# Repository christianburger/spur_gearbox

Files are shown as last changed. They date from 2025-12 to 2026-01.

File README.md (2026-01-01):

# Spur Gearbox for NEMA17 Motor

A fully parametric **3D printable single-stage spur gear reduction gearbox** designed in OpenSCAD, intended for NEMA17 stepper motors.

This design provides a clean, compact reduction using chamfered spur gears for smoother meshing, supported by 695ZZ bearings (5x13x4 mm). The split housing allows easy assembly, and the output shaft is designed for a 9 mm round shaft with setscrew.

**Gear ratio**: 32:12 ≈ **2.667:1** reduction

## Features

- Direct mount to standard NEMA17 motors (31 mm hole pattern)
- Input gear with D-shaft bore for standard 5 mm motor shafts
- Chamfered gears to reduce sharp edges and improve print quality/meshing
- Integrated bearing pockets and retainers for two 695ZZ bearings
- Setscrew hubs on both input and output gears
- Mounting holes on the output end (M4)
- Printed in two halves (top + bottom housing) for easy access

## Files

- `complete.gearbox.scad` – Full assembly view (open this to preview the complete gearbox)
- `housing_bottom.scad` – Bottom half of the housing
- `housing_top.scad` – Top half of the housing
- `input_gear_chamfered.scad` – Input gear (12 teeth) with hub and D-bore
- `output_gear_chamfered.scad` – Output gear (32 teeth) with hub
- `.stl` files – Pre-exported meshes ready for slicing/printing

## How to Generate STL Files and 3D Print

### Using OpenSCAD (recommended for latest/custom versions)

1. Install OpenSCAD (free from https://openscad.org/)
2. Open each part file you want to print:
   - `housing_bottom.scad`
   - `housing_top.scad`
   - `input_gear_chamfered.scad`
   - `output_gear_chamfered.scad`
   - (Optional: open `complete.gearbox.scad` first to preview the full assembly)
3. Press **F5** to preview the model
4. Press **F6** to render (this computes the full geometry – takes a few seconds)
5. Once rendered, go to **File > Export > Export as STL** and save the file
6. Repeat for each part

### Using Pre-exported STLs

The repository already includes ready-to-print STL files for all parts. Simply download them directly.

### Slicing and Printing Recommendations

- **Material**: PETG or PLA+ recommended for strength and durability (ABS/ASA also good if you have an enclosure)
- **Layer height**: 0.15–0.2 mm for good balance of strength and detail
- **Infill**: 30–50% (use more for gears if under heavy load)
- **Perimeters/Walls**: 3–4 for strength
- **Supports**: Usually minimal or none needed. Small tree supports may help under bearing bosses if your printer struggles with bridging
- **Orientation**: Print housing halves flat on the bed (large flat side down) for best strength
- **Brim**: Recommended for better bed adhesion on larger parts

## Required Hardware

- 2 × 695ZZ bearings (5 × 13 × 4 mm)
- M3 grub screw for input gear setscrew
- M4 or M5 grub screw for output shaft
- Optional: M3/M4 screws or glue to secure top and bottom housing together

## Customization

Parameters are defined at the top of the SCAD files. You can easily modify:
- Gear ratio (change tooth counts)
- Module (tooth size)
- Shaft diameters
- Clearances and tolerances for your printer

Open `complete.gearbox.scad` to visualize changes in the full assembly.

Enjoy the build! If you print it, feel free to share improvements. 🚀

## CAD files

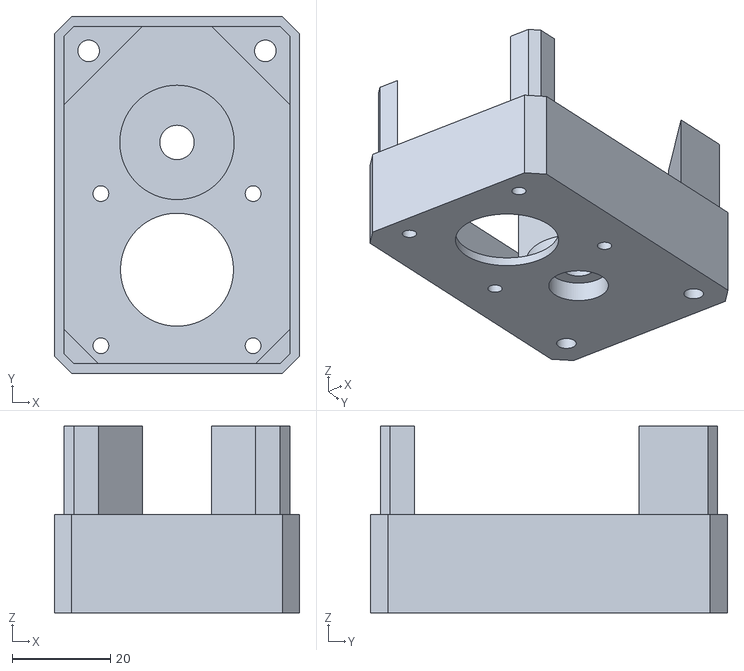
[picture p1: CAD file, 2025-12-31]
housing_bottom.stl
50.0 x 72.7 x 38.0

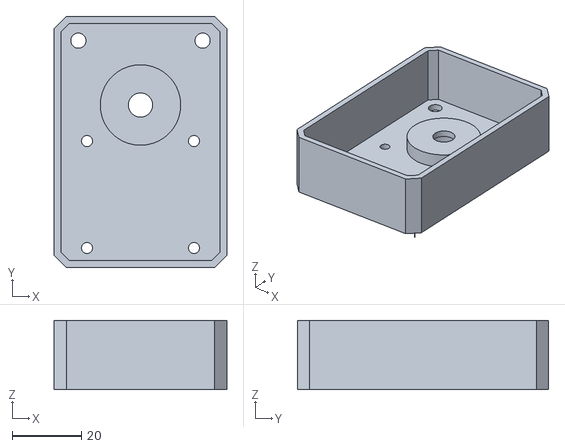
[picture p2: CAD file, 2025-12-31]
housing_top.stl
50.0 x 72.7 x 20.0

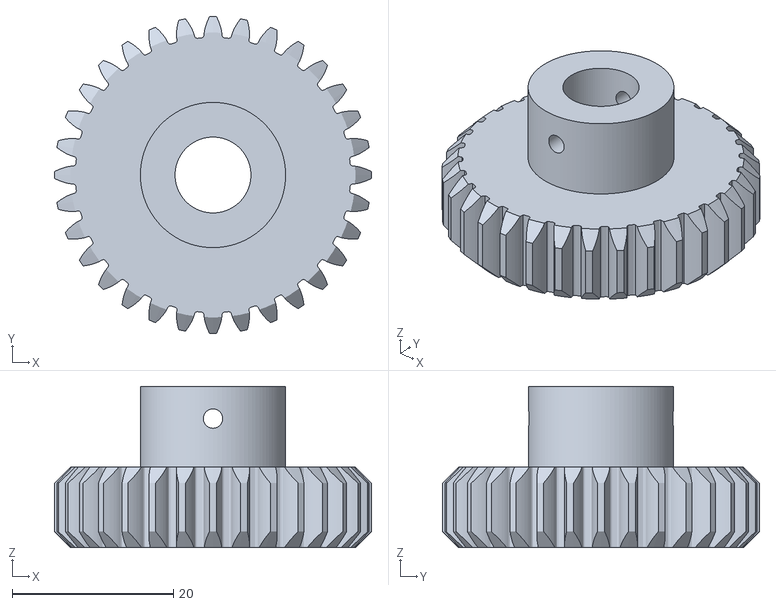
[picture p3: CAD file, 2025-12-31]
output_gear_chamfered.stl
39.3 x 39.3 x 20.0

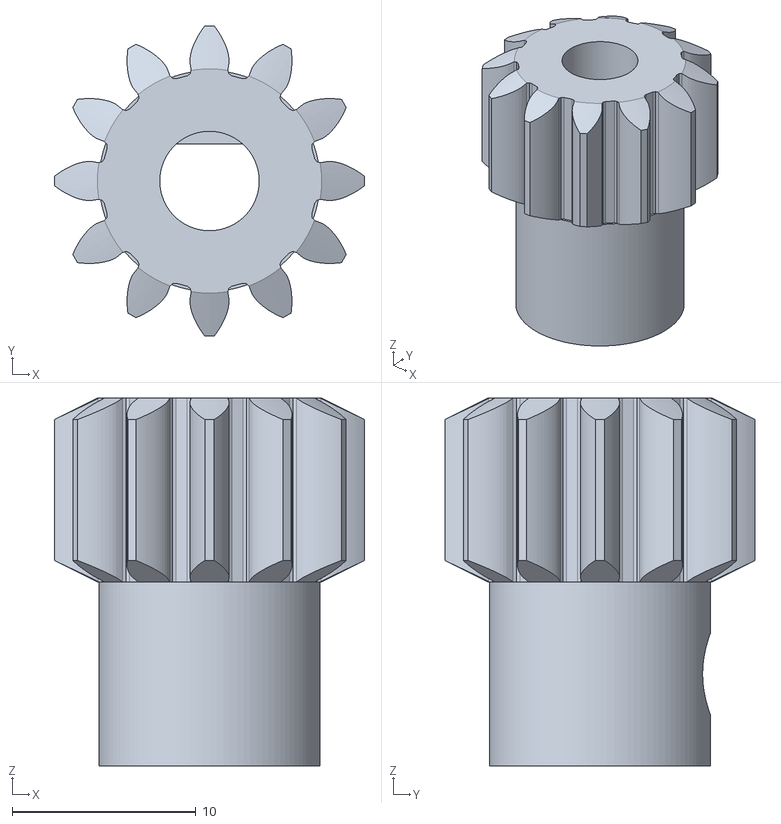
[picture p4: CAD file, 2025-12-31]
input_gear_chamfered.stl
16.9 x 16.9 x 20.0

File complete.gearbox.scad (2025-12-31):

// ============================================================================
// 4:1 LINEAR GEARBOX HOUSING
// ============================================================================
// BOSL2 library required
// Print TWICE to get both halves (identical halves)
// ============================================================================

include <BOSL2/std.scad>
include <BOSL2/gears.scad>

$fn = 100;

// ============================================================================
// TOLERANCES & CLEARANCES
// ============================================================================
// Clearance: Add to pockets/holes (makes them bigger for fit)
// Tolerance: Add to shaft bores (allows shaft to pass through)

clearance_bearing_pocket = 0.3;  // Bearing pocket clearance
clearance_screw_hole = 0.0;      // M3 screw hole clearance
clearance_boss_center = 0.3;     // Motor boss center clearance
tolerance_shaft = 0.4;           // Shaft bore tolerance
tolerance_output_bore = 0.4;     // Output gear bore tolerance

// ============================================================================
// GEAR PARAMETERS
// ============================================================================

teeth_input = 12;
teeth_output = 32;
gear_module = 1.156;
gear_thickness = 10;
gear_pressure_angle = 20;

// Calculated gear dimensions
pitch_radius_input = (gear_module * teeth_input) / 2;
pitch_radius_output = (gear_module * teeth_output) / 2;
outer_radius_input = (gear_module * (teeth_input + 2)) / 2;
outer_radius_output = (gear_module * (teeth_output + 2)) / 2;
center_distance = pitch_radius_input + pitch_radius_output + 0.5;

// ============================================================================
// BEARING SPECIFICATIONS (695ZZ: 5mm ID, 13mm OD, 4mm thickness)
// ============================================================================

bearing_id = 5;      // Inner diameter
bearing_od = 13;     // Outer diameter
bearing_thickness = 4;

// ============================================================================
// SHAFT & HUB PARAMETERS
// ============================================================================

// Input shaft (D-shaped)
shaft_diameter_input = 5.0;
shaft_flat_height = 4.0;  // D-shaft flat dimension
hub_diameter_input = 12;
hub_height_input = 10;

// Output shaft (round)
shaft_diameter_output = 9.0;
hub_diameter_output = 18;
hub_height_output = 10;

// Setscrews (M3 grub screws)
setscrew_output_diameter = 3.0;
setscrew_output_clearance = 0.6;  // Undersize for PETG shrinkage

// Setscrews (M5 grub screws)
setscrew_input_diameter = 5.0;
setscrew_input_clearance = 0.6;  // Undersize for PETG shrinkage

// Gear chamfers
chamfer_height = 2.0;
chamfer_angle = 45;
chamfer_base_radius_input = outer_radius_input - chamfer_height * tan(chamfer_angle);
chamfer_base_radius_output = outer_radius_output - chamfer_height * tan(chamfer_angle);
chamfer_base_radius_gear = outer_radius_input + 2;

// ============================================================================
// NEMA17 MOTOR PARAMETERS
// ============================================================================

nema17_body_size = 42.3;          // Standard NEMA17 body dimension
nema17_hole_spacing = 31;         // Mounting hole spacing
nema17_hole_diameter = 3.2;       // M3 mounting holes
nema17_boss_diameter = 23;        // Center boss clearance
nema17_boss_depth = 2.5;          // Boss pocket depth
nema17_hole_edge_distance = 5.65; // Distance from hole center to motor edge

// ============================================================================
// HOUSING DIMENSIONS
// ============================================================================


wall_to_gear_clearance = 6;
housing_width = 50;                // X dimension (matches NEMA17)

//housing_length = 56;

wall_thickness = 2;
floor_thickness = 2;

// Bearing pockets
bearing_pocket_depth = bearing_thickness + 0.5;
bearing_retainer_height = 2.0;     // Retainer ring height
bearing_retainer_id = 7.0;         // Retainer inner diameter
boss_diameter = bearing_od + clearance_bearing_pocket + 10;

clearance_internal_bottom = 1.5;   // Clearance below gears
clearance_internal_top = 1.5;      // Clearance above gears

box_height = (floor_thickness * 2 +          
              clearance_internal_bottom + 
              clearance_internal_top +
              max(hub_height_input, hub_height_output) + 
              gear_thickness + 
              bearing_retainer_height * 2 +
              bearing_pocket_depth * 2) / 2;

   
echo ("clearance_internal_bottom: ", clearance_internal_bottom)
echo ("clearance_internal_top", clearance_internal_top);
echo ("hub_height (max)", max(hub_height_input, hub_height_output));
echo ("gear_thickness: ", gear_thickness)
echo ("bearing_retainer_height (x2): ", bearing_retainer_height * 2);
echo ("bearing_pocket_depth: (x2)", bearing_pocket_depth * 2);   
echo ("\n\n>>>>> box_height: ", box_height);

// ============================================================================
// CALCULATED POSITIONS
// ============================================================================

// Input shaft position (centered on NEMA17 mounting pattern)
input_x = housing_width / 2;
input_y = nema17_hole_edge_distance + nema17_hole_spacing / 2;

// Output shaft position
output_x = input_x;
output_y = input_y + center_distance;

housing_length = output_y + outer_radius_output + wall_to_gear_clearance;


// NEMA17 mounting holes (31mm square pattern)
nema17_hole1_x = input_x - nema17_hole_spacing / 2;
nema17_hole1_y = input_y - nema17_hole_spacing / 2;
nema17_hole2_x = input_x + nema17_hole_spacing / 2;
nema17_hole2_y = input_y - nema17_hole_spacing / 2;
nema17_hole3_x = input_x - nema17_hole_spacing / 2;
nema17_hole3_y = input_y + nema17_hole_spacing / 2;
nema17_hole4_x = input_x + nema17_hole_spacing / 2;
nema17_hole4_y = input_y + nema17_hole_spacing / 2;

// Output end mounting holes (opposite end)
output_hole_edge_distance = 7;    // Distance from output hole center to wall edge
output_hole_diameter = 4.2;       // M4 mounting holes at output end
output_hole_tolerance = 0.2;      //clearance for M4 mounting holes at output end

output_hole1_x = output_hole_edge_distance;
output_hole1_y = housing_length - output_hole_edge_distance;
output_hole2_x = housing_width - output_hole_edge_distance;
output_hole2_y = housing_length - output_hole_edge_distance;

// corner chamfer   
box_chamfer_width = wall_thickness;
   

module corner_chamfer(box_chamfer_width, box_chamfer_size) {
  cube([box_chamfer_width, box_chamfer_size, box_height]);
}

// ==========================
// Helper function
// ==========================
function polar(len, angle_deg) =
    [ len * cos(angle_deg), len * sin(angle_deg) ];

// ==========================
// Module output_corner_reinforcement
// ==========================
module output_corner_reinforcement(chamfer_len, line_len, height)
{
    // Reference chamfer (XY plane, z = 0)
    p0 = [0, 0];
    p1 = [chamfer_len, 0];

    // Constructed edges
    p2 = p1 + polar(line_len,  45);   // +45° from right chamfer point
    p3 = p0 + polar(line_len, 135);   // 135° from left chamfer point

    // Extrude from z = 0 to z = height
    linear_extrude(height = height)
        polygon(points = [
            p0,
            p1,
            p2,
            p3
        ]);
}

box_chamfer_size = 5; 
line_len = 14;
internal_chamfer_len = 2 * wall_thickness / sqrt(2);

local_hole_x = wall_thickness * (sqrt(2) / 2);
local_hole_y = (2 * output_hole_edge_distance - 3 * wall_thickness) * (sqrt(2) / 2);
hole_diam = output_hole_diameter + output_hole_tolerance;
    
reinforcement_height = box_height * 2 - floor_thickness;


// Visualization offsets
z_offset_top_housing = 100;
z_offset_gears = 20;

// ============================================================================
// BOTTOM HOUSING HALF
// ============================================================================
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

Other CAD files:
housing_bottom.scad
housing_top.scad
input_gear_chamfered.scad
output_gear_chamfered.scad

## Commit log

2025-12-26 semi functional gears and enclosure.
    [complete.gearbox.scad, housing_bottom.scad, housing_top.scad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]
2025-12-26 adjusted dimensions, shapes, fixed variable names.
    [input_gear.scad, input_gear.stl, only_gears.scad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]
2025-12-27 semi-functional housing.
    [complete.gearbox.scad, housing_bottom.scad, housing_top.scad]
2025-12-28 added taper to avoid supports.
    [complete.gearbox.scad, housing_bottom.scad, housing_top.scad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]
2025-12-29 refactored output gear for brass inserts.
    [complete.gearbox.scad, housing_bottom.scad, housing_top.scad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]
2025-12-29 fixed box dimensions, adjusted gears for shaft inserts.
    [complete.gearbox.scad, housing_bottom.scad, housing_top.scad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]
2025-12-29 implemented one of the chamfers.
    [housing_bottom.scad]
2025-12-29 added chamfers for all corners of the bottom housing.
    [housing_bottom.scad]
2025-12-29 chamfered boxes complete.
    [complete.gearbox.scad, housing_top.scad]
2025-12-30 resized and repositioned output screw mounts.
    [complete.gearbox.scad]
2025-12-30 one corner with reinforcemnt.
    [complete.gearbox.scad]
2025-12-30 reinforcement chamfers in place.
    [complete.gearbox.scad]
2025-12-30 minor fixes and improvements.
    [complete.gearbox.scad, housing_bottom.scad, housing_bottom.stl]
2025-12-30 updated housing_top.scad with changes also.
    [housing_top.scad]
2025-12-31 changed dimensions again.
    [complete.gearbox.scad, housing_bottom.scad, housing_bottom.stl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]
2025-12-31 resized housing and few other corrections.
    [complete.gearbox.scad, housing_bottom.scad, housing_bottom.stl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]
